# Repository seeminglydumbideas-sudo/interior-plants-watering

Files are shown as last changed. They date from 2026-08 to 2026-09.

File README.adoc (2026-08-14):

= Interior Plants Watering System

A comprehensive plant monitoring and automated watering system based on the ESP32 platform. This project consists of low-power Bluetooth Low Energy (BLE) moisture sensors distributed across your plants, and a central base station that aggregates data, provides a monitoring interface, and controls water pumps to keep your plants happy.

== Status

As of Summer 2026, active development is primarily focused on finalizing the sensor nodes. The immediate goals are to ensure their reliability and to design a 3D-printable enclosure for them. The central server does not yet control the water pumps; it currently features a minimal UI and exposes a Prometheus endpoint. For the time being, sensor data is observed and troubleshooted primarily via Grafana dashboards.

[cols="1,1,1", frame="none", grid="none"]
|===
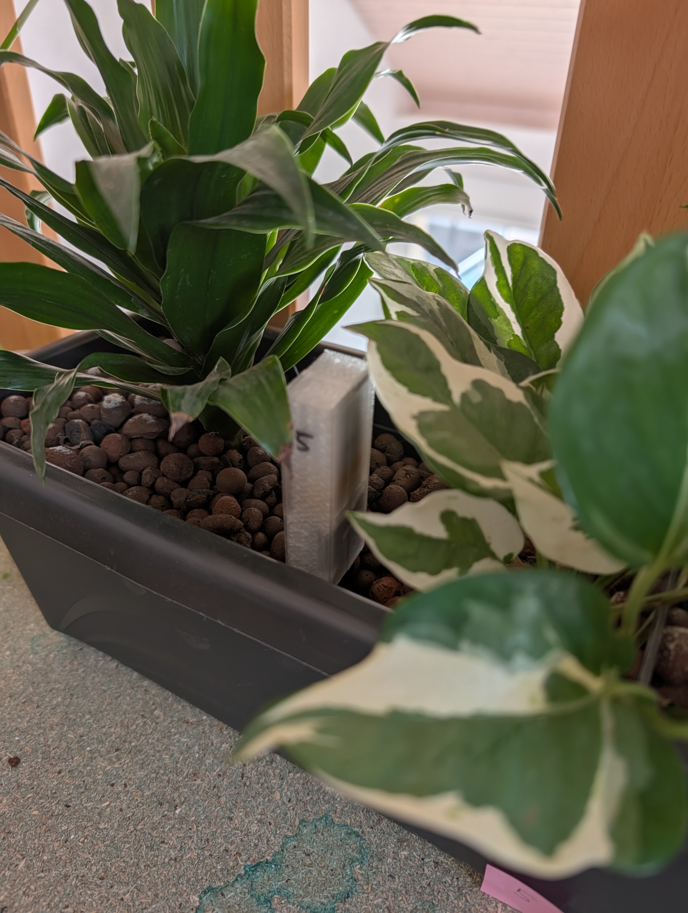
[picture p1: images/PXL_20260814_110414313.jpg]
| 
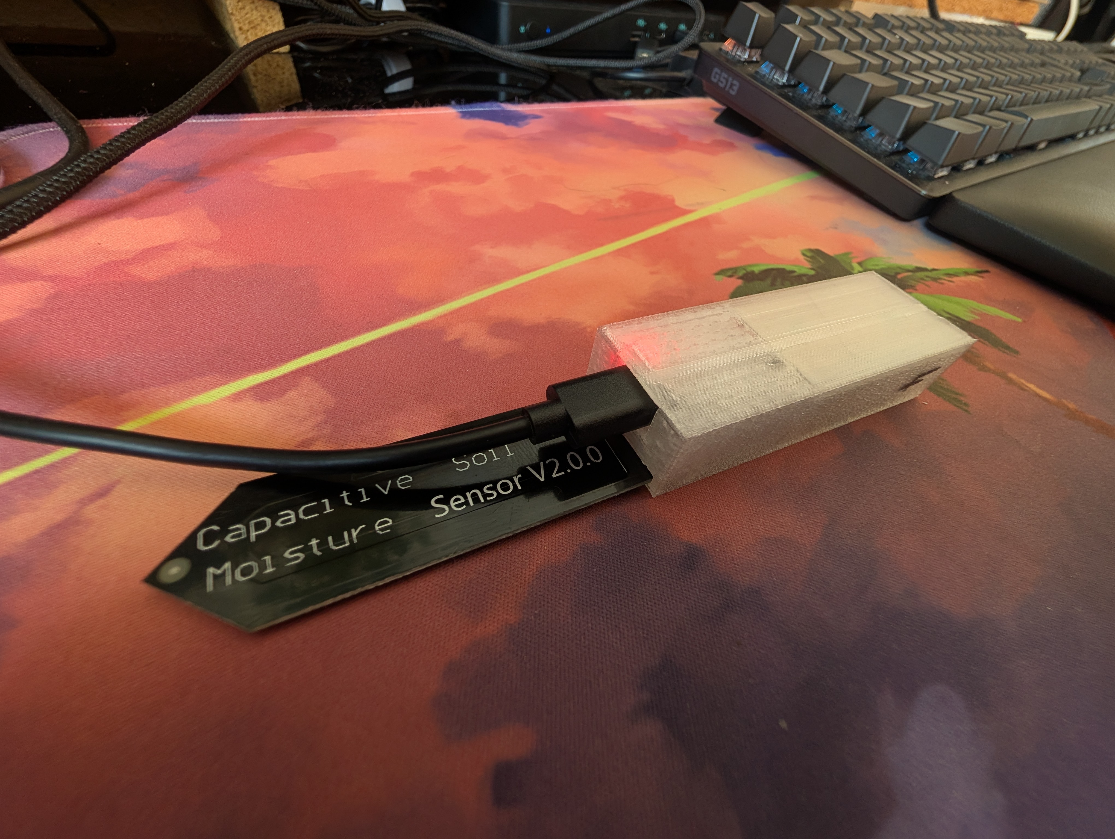
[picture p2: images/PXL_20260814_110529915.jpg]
| 
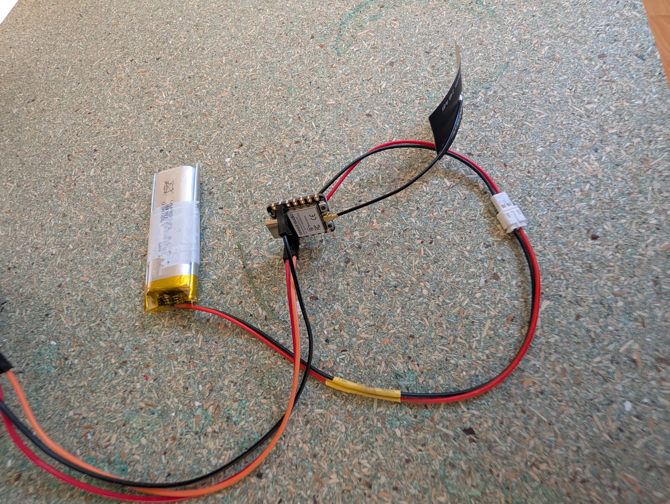
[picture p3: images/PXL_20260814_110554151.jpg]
| 

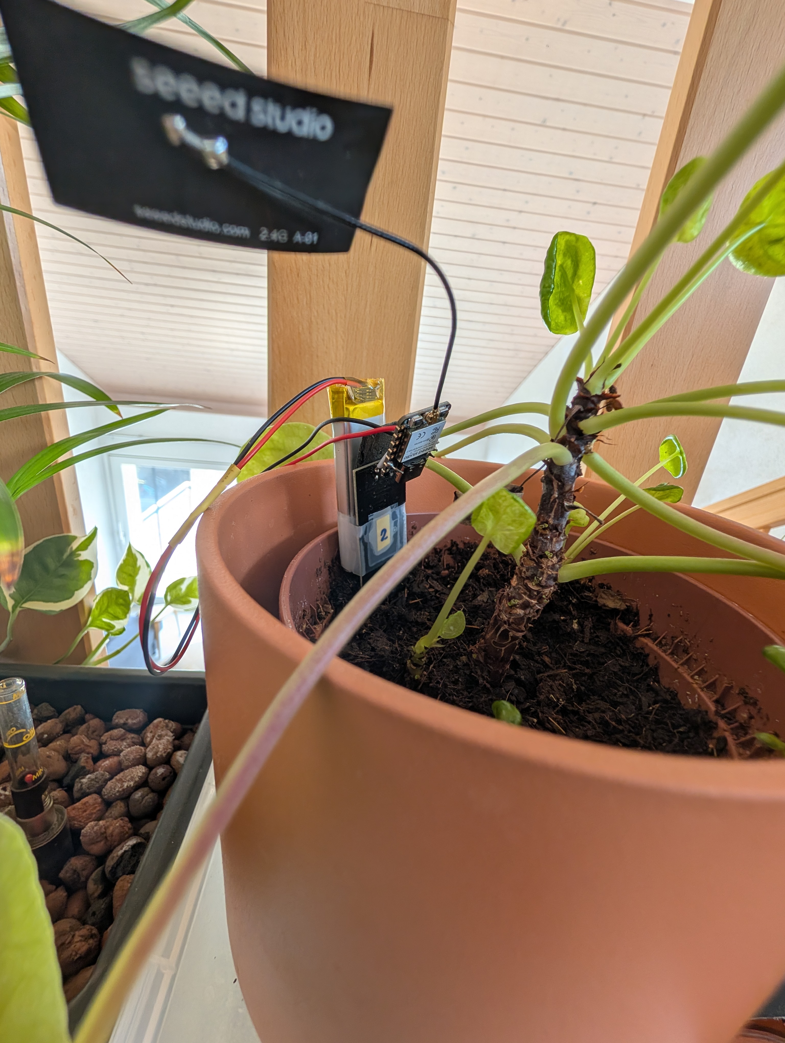
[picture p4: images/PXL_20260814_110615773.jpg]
| 
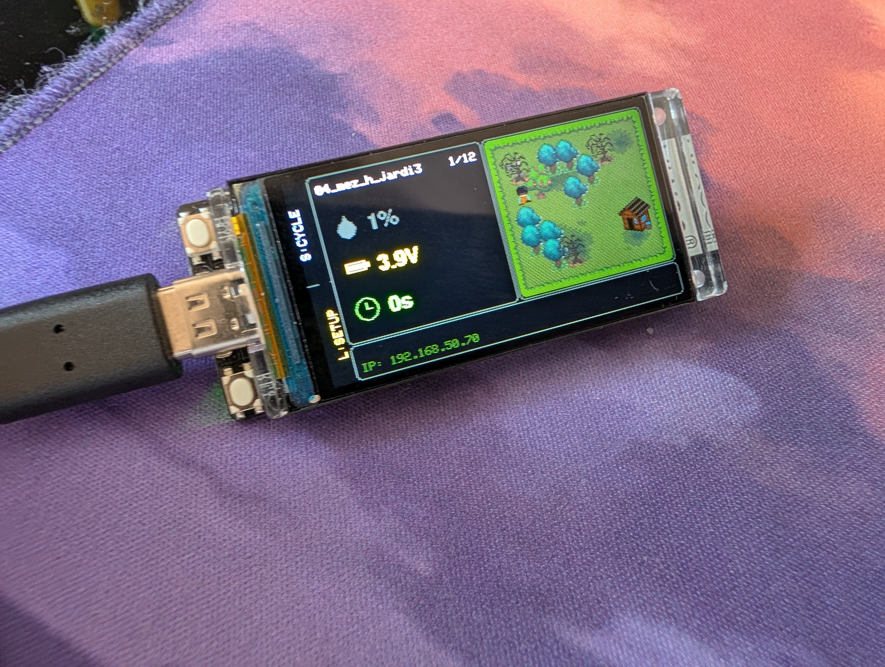
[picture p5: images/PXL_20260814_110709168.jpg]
| 
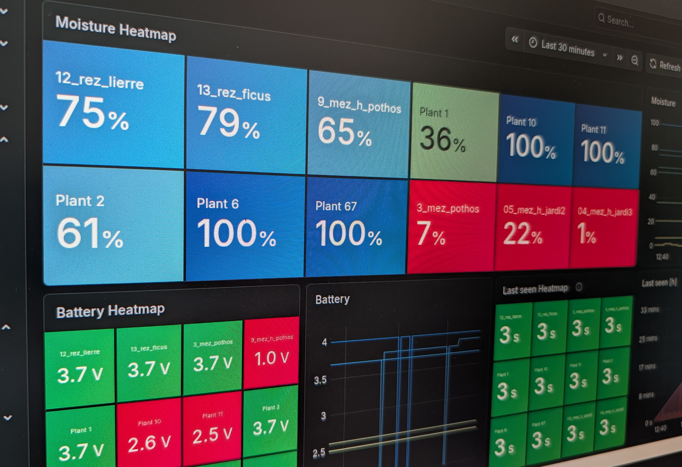
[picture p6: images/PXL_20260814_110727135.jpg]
| 
|===

== System Architecture

The system is split into two main components, which will be integrated into this repository:

=== 1. Plant Sensor (The "Nodes")
A low-power BLE soil moisture sensor node. Designed for battery-powered deployment, it spends most of its life in deep sleep, waking periodically to sample soil moisture and broadcast telemetry.

See the link:sensor/README.adoc[Sensor Documentation] for detailed hardware configuration, pinouts, and calibration instructions.

* *Hardware:* Seeed Studio XIAO ESP32-C3, Capacitive Soil Moisture Sensor v1.2, 3.7V LiPo battery.
* *Features:* 
** Broadcasts telemetry via BLE manufacturer advertisements (no active connection required).
** Auto-calibration of dry/wet bounds stored in NVS flash.
** Battery voltage monitoring and smart power management (differentiates between USB and battery).

=== 2. Plant Server (The "Base Station")
The central controller that scans for BLE advertisements from the sensors, displays their status, and triggers water pumps when plants get too dry.

* *Hardware:* LilyGo T-Display ESP32 (or ESP32-S3), 4-channel relay board, and water pumps.
* *Features:*
** *Monitoring UI:* A clean data-focused display to monitor the real-world sensors.
** *Automated Watering:* Controls relays based on moisture readings with safety cooldowns and scheduling logic.
** *Metrics:* Serves Prometheus metrics for monitoring via Grafana.
** *Persistence:* Thread-safe sensor data management with NVS persistence for configuration and last-watered times.

== How It Works

1. *Sensors* read capacitive moisture levels and broadcast the raw data, calibration bounds, and battery voltage over BLE using a specific Service UUID (`a1b2c3d4-0001-4c9a-8f2e-5a7b9e3d6f80`).
2. The *Server* continuously scans the BLE spectrum for these specific advertisements.
3. The *Server* parses the data, updates its internal thread-safe store, and updates the display.
4. If a sensor's moisture drops below a threshold, the *Server's* Gardener module activates the corresponding relay to run a water pump.

== Getting Started

Each component has its own specific build instructions, configuration, and hardware setup. Please refer to the respective subdirectories (once imported) for detailed setup and deployment instructions.

* *For deploying a new sensor node:* You will need a XIAO ESP32-C3 and the Arduino IDE / `arduino-cli` to compile and upload the firmware. See the link:sensor/README.adoc[Sensor Setup Guide].
* *For setting up the base station:* You will need a LilyGo T-Display, WiFi credentials (for metrics), and the appropriate Arduino libraries (like `TFT_eSPI` configured for your display).

== License

This project is licensed under the GNU General Public License v3.0 (GPL-3.0). See the LICENSE file for details.

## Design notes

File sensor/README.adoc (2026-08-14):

= plant-sensor-esp32

A low-power Bluetooth Low Energy (BLE) soil moisture sensor node built for the *Seeed Studio XIAO ESP32-C3*.

== Overview

`plant-sensor-esp32` periodically measures soil moisture levels, monitors battery voltage and power source, and broadcasts telemetry over BLE manufacturer advertisements. Designed for battery-powered deployment, the device spends most of its life in ESP32 deep sleep, waking up to sample sensors and advertise data to central receiver nodes (such as the Plant Server).

IMPORTANT: Sensors are designed to be used with a dedicated base station (not used directly with phones). See the link:../README.adoc[main project README] for details.

=== Hardware Components

* *Microcontroller:* Seeed Studio XIAO ESP32-C3 (RISC-V single-core @ 160MHz, 2.4GHz Wi-Fi & BLE 5.0)
* *Soil Moisture Sensor:* Capacitive Soil Moisture Sensor v1.2
* *Power Monitoring:* Voltage divider (2x 220kΩ resistors) connected to ADC pin `D2` / `A2`
* *Power Supply:* 3.7V LiPo / Li-Ion battery or USB-C (5V)

== Key Features

* *BLE Telemetry Broadcast:* Broadcasts sensor telemetry without requiring active connections. Scan response manufacturer data payload includes:
** Moisture percentage (`0–100%`, or uncalibrated indicator `0xFF`)
** Raw ADC reading, `rawMin`, and `rawMax` bounds
** Battery voltage (`V`) and power source (Battery vs. USB)
** RTC boot counter
** Filterable by Service UUID `a1b2c3d4-0001-4c9a-8f2e-5a7b9e3d6f80`
* *Capacitive Moisture Sampling:* Non-blocking async sampling state machine to power and sample the sensor safely. Automatically tracks calibration bounds and persists them to NVS flash (`Preferences`).
* *Smart Power Management:* Reads battery voltage via resistor divider on ADC pin `D2`, differentiates between USB and battery power, and controls ESP32 deep sleep cycles. Features a 2-minute safety window on cold power-on to allow seamless firmware reflashing.
* *Calibration Reset:* Press and hold the onboard *BOOT* button (GPIO 9) for 3 seconds to clear saved calibration bounds from flash memory.

== Pinout & Hardware Configuration

[cols="1,1,2", options="header"]
|===
| Component | Pin | Notes

| *Moisture Sensor VCC*
| `D0`
| Switched output to power sensor only during sampling

| *Moisture Sensor Signal*
| `D1`
| Analog input for moisture sensor reading

| *Battery Divider ADC*
| `D2` / `A2`
| Resistor divider input for voltage measurement

| *BOOT Button*
| `GPIO 9`
| Pulled HIGH internally; hold 3s to reset calibration
|===

== Calibration Procedure

The sensor uses automatic bound tracking to calculate soil moisture percentages from raw ADC readings. The bounds (`rawMin` and `rawMax`) are stored in NVS flash memory (`Preferences`). It will persist resets and re-deploy.

To calibrate a sensor:

1. *Wake Device:* Press the *RST button* (or power-cycle the board) to ensure the ESP32 is awake and not in deep sleep mode.
2. *Reset Calibration:* Press and hold the onboard *BOOT button (GPIO 9)* for 3 seconds. The serial output will log `[INFO] Moisture calibration reset`, clearing stored bounds (`rawMin = 4095`, `rawMax = 0`).
3. *Set Dry Bound (0%):* Expose the capacitive probe to dry air (or insert into completely dry soil) during a sample cycle (typically 2-4 minutes). The highest ADC value measured will automatically be saved as `rawMax`.
4. *Set Wet Bound (100%):* Submerge the probe in water up to the max fill line (or insert into fully saturated soil) during a sample cycle. The lowest ADC value measured will automatically be saved as `rawMin`.
5. *Automatic Calculation:* Once `rawMax > rawMin + 500`, the firmware calculates moisture as:
+
[source,cpp]
----
moisture % = 100 - ((100 * (rawValue - rawMin)) / (rawMax - rawMin))
----
+
Updated calibration bounds are saved to flash memory automatically whenever new minimums or maximums are detected.

== Build & Deployment

Use the provided `deploy.sh` script (located in the `bin/` directory) to compile, upload, and monitor. Make sure to run it from inside the `sensor/` directory:

[source,bash]
----
# Compile and upload specifying the SENSOR_ID
SENSOR_ID=13_rez_ficus ./bin/deploy.sh /dev/ttyACM0

# Compile only
SENSOR_ID=13_rez_ficus ./bin/deploy.sh --compile-only
----

The script automatically generates `Secrets.cpp` containing your specified `SENSOR_ID` and attaches to the serial monitor.

== License

This project is licensed under the GNU General Public License v3.0 (GPL-3.0) - see the link:../LICENSE[LICENSE] file in the root directory for details.

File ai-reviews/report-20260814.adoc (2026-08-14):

= AI Pre-Commit Review Report: Interior Plants Watering
:date: 2026-08-14
:author: Antigravity AI
:toc:

== 1. Privacy, Security & Secrets (AGENTS.md Checklist)
=== 1.1 Hardcoded Secrets
* [PASS] No hardcoded passwords, SSIDs, or API tokens were found leaked in the repository.
* [PASS] `Secrets.h` is used properly for definitions, while `Secrets.cpp` is kept out of source control.
* [NOTE] In `.gitignore`, `Secrets.cpp` is listed twice (lines 2 and 3). This is harmless but could be cleaned up.

=== 1.2 PII & Absolute Paths
* [PASS] No absolute local paths (`/home/user/...`), usernames, or IP leaks were detected in the source code or scripts.

=== 1.3 Media Metadata (EXIF)
* [WARNING] Several `.jpg` and `.png` files in the `images/` and `sensor/3d_case/` directories still contain residual EXIF metadata (e.g., `Modify Date`, `Pixels Per Unit`, `Image Size`).
  * **Recommendation:** Run `find . -type f -name "*.png" -o -name "*.jpg" | xargs exiftool -all=` from the root directory before committing to adhere strictly to the Open Source Checklist.

== 2. Code Architecture & Power Management (`sensor-firmware`)
=== 2.1 Deep Sleep Implementation
* [PASS] `PowerManager.cpp` correctly implements deep sleep using `esp_deep_sleep_start()`.
* [PASS] The system appropriately uses `RTC_DATA_ATTR` for variables like `bootCount` and `totalElapsedSec` to survive deep sleep cycles and reset only on cold power cycles.

=== 2.2 Non-Blocking Architecture
* [PASS] `sensor-firmware.ino` avoids blocking `delay()` loops for its core state machine, cleanly separating logic across `power.loop()`, `moisture.loop()`, `bluetooth.loop()`, and `sensor.loop()`.
* [PASS] The broadcast window relies on `millis()` tracking (`millis() - _dataReadyAt < BROADCAST_WINDOW_MS`) before entering deep sleep, ensuring BLE packets have time to transmit.

=== 2.3 Hardware Interfaces
* [PASS] Voltage readings correctly take attenuation and multi-sampling into account in `PowerManager::getLevel()`.

== 3. Documentation
* [PASS] `README.adoc` provides excellent, comprehensive overviews of both the Sensor ("Nodes") and the Server ("Base Station") components.
* [PASS] The documentation accurately reflects the current state of development (Summer 2026, pumps disabled, Prometheus/Grafana focus).

== Summary & Recommendations
The `interior-plants-watering` sensor implementation is very clean, utilizing proper low-power design patterns for the ESP32-C3. 

**Action Item Before Commit:** Scrub the remaining EXIF data from the image directories.

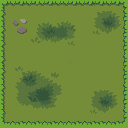
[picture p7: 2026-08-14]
server/server-firmware/sprites/scene.png

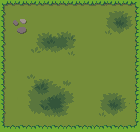
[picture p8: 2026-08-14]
server/server-firmware/sprites/scene2.png

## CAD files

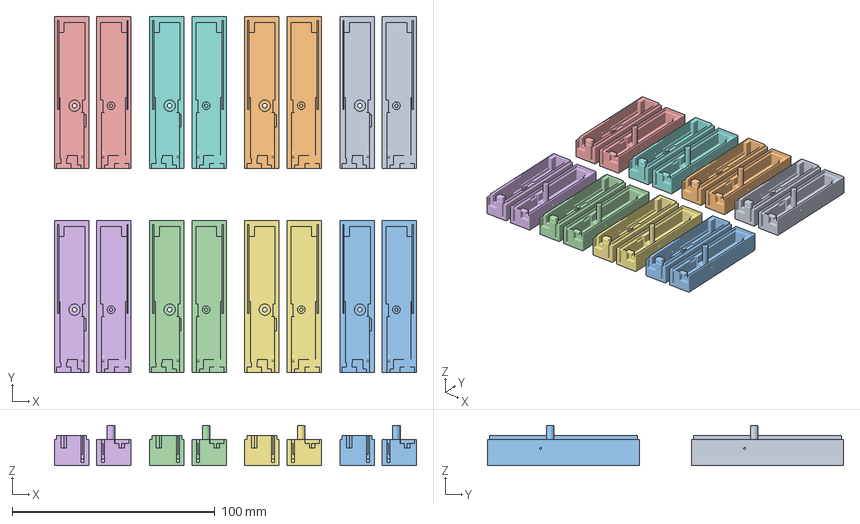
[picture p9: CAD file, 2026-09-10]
sensor/3d_case/plant_v8.2/plant_v8.2.3mf
178.5 x 175.6 x 19.9 mm
plant_8,2.stl x 5
plant_8,2.stl 1
plant_8,2.stl 6
plant_8,2.stl 4

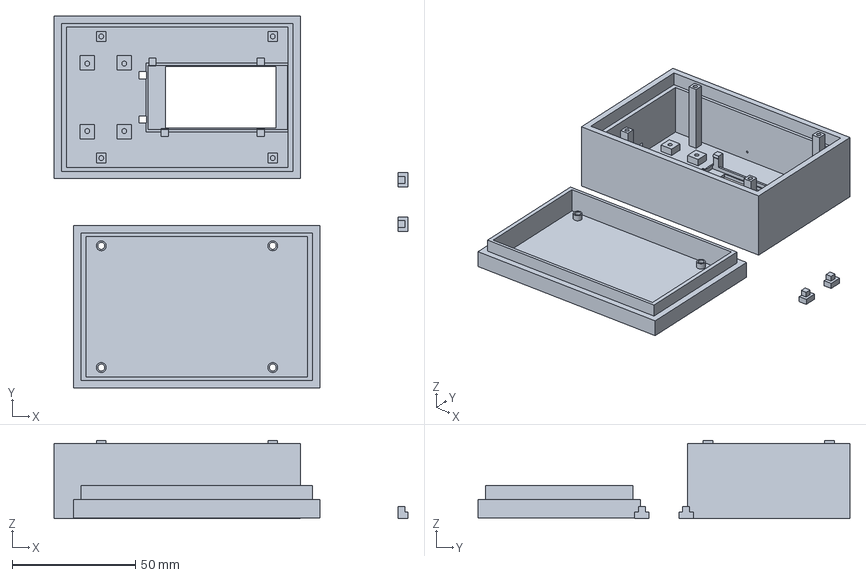
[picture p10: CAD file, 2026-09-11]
server/3d_case/pltsrv_v1.1/pltsrv_v1.1.3mf
143.7 x 151.0 x 31.7 mm

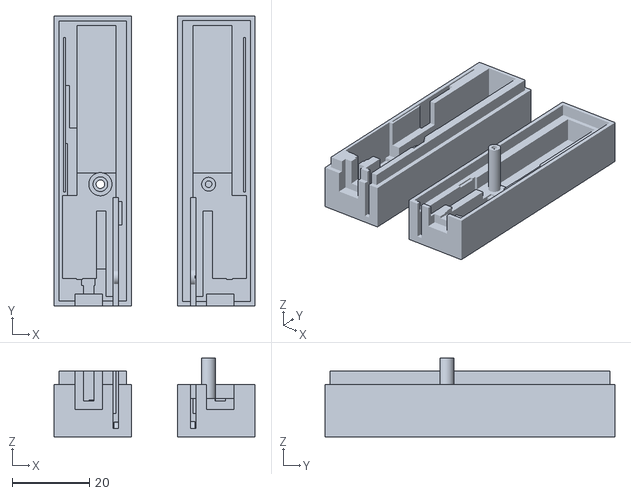
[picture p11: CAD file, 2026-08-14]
sensor/3d_case/plant_v7.x/plant_v7.0-fat.stl
52.0 x 75.0 x 20.4

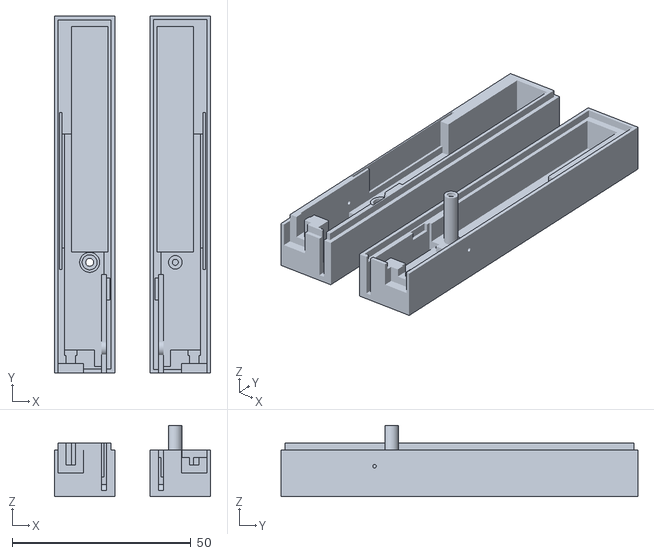
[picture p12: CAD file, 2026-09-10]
sensor/3d_case/plant_v8.2/plant_8,2-large_battery.stl
43.8 x 100.0 x 19.9

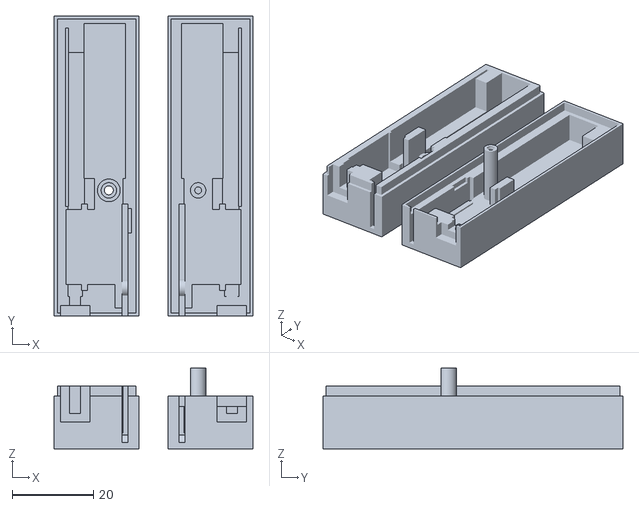
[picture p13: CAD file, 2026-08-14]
sensor/3d_case/plant_v7.x/plant_v7.5-avoid_thin_walls.stl
48.9 x 73.9 x 19.8

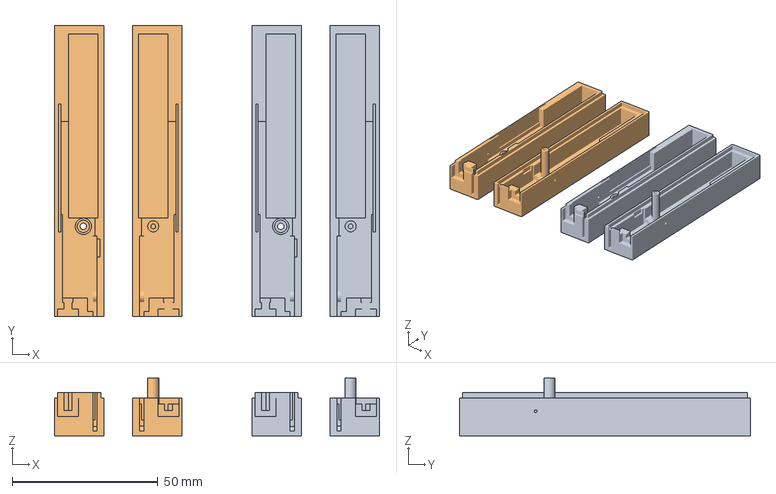
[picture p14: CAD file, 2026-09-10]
sensor/3d_case/plant_v8.2/plant_v8.2_large-battery.3mf
111.6 x 100.0 x 19.9 mm
plant_8,2-large_battery.stl x 2

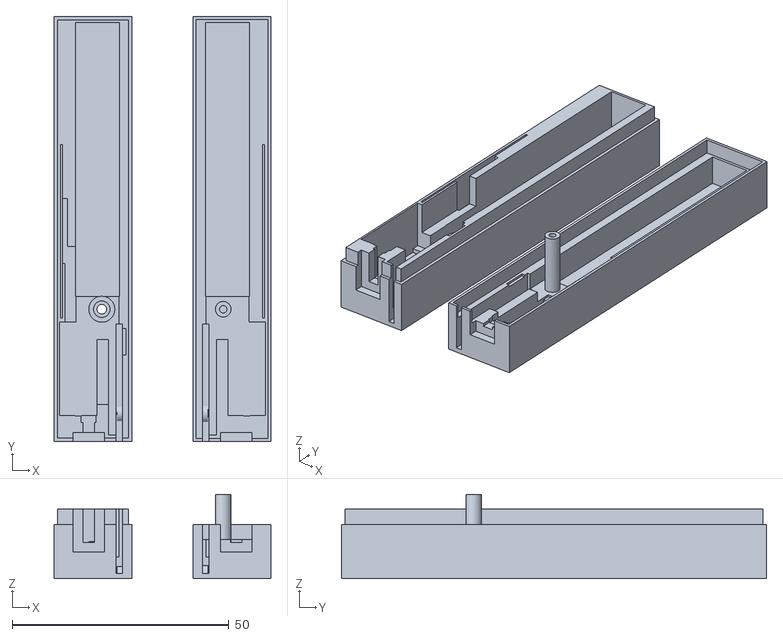
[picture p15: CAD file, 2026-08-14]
sensor/3d_case/plant_v7.x/plant_v7.0-large.stl
50.0 x 98.0 x 19.4

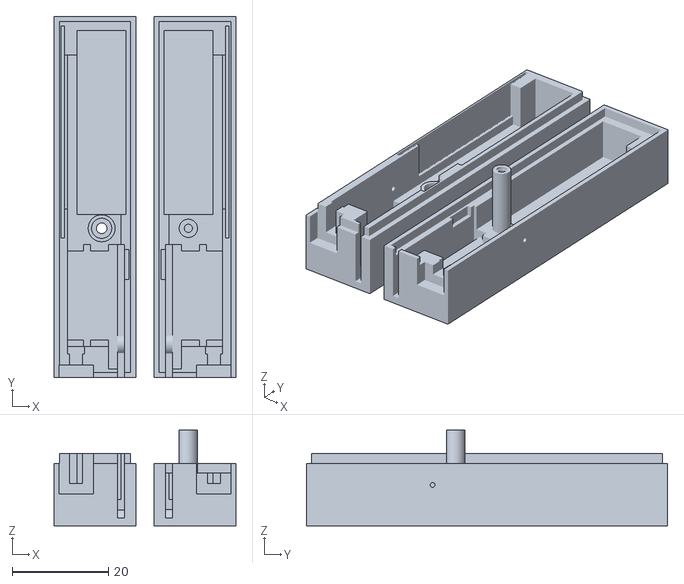
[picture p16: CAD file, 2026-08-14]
sensor/3d_case/plant_v8.2/plant_8,2.stl
37.8 x 75.0 x 19.9

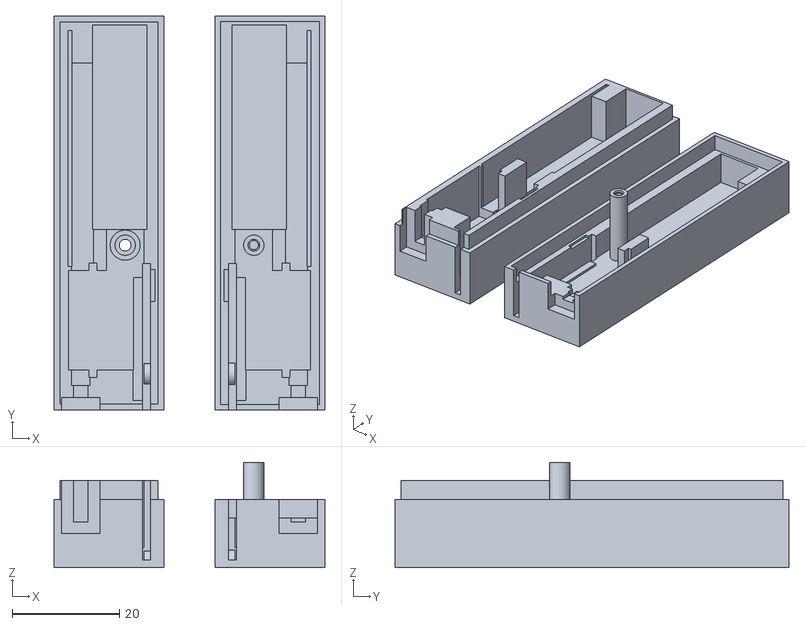
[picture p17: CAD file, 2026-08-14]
sensor/3d_case/plant_v7.x/plant_v7.4.stl
50.5 x 73.5 x 19.6

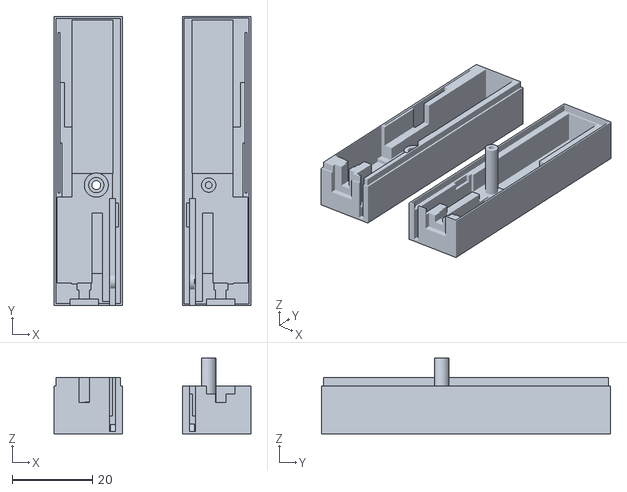
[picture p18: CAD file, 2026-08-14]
sensor/3d_case/plant_v7.x/plant_v7.0-thin.stl
49.0 x 72.0 x 18.9

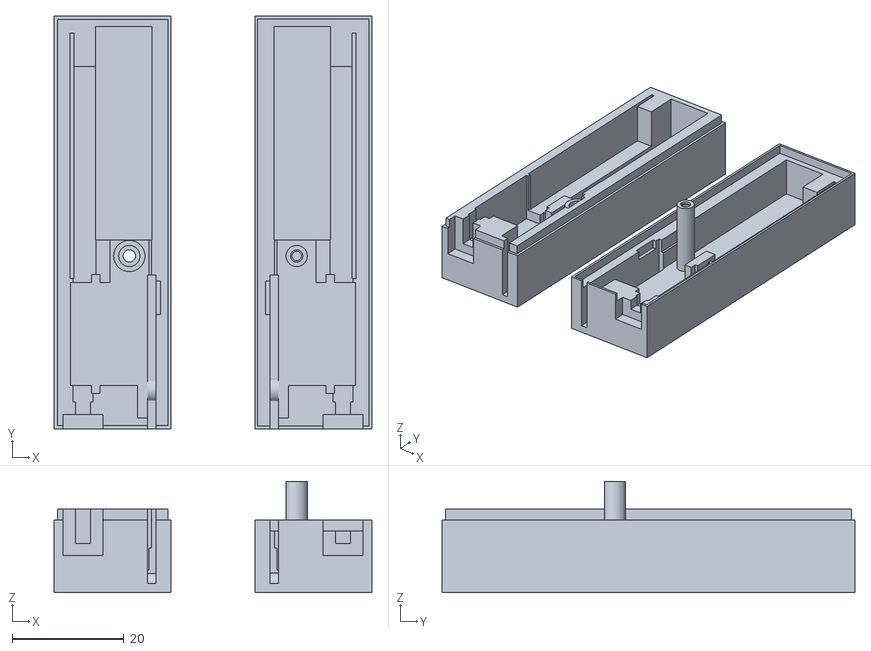
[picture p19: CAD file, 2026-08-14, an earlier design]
sensor/3d_case/plant_v8.0/plant_8.0-avoid-thin-walls.stl
57.0 x 74.0 x 19.9

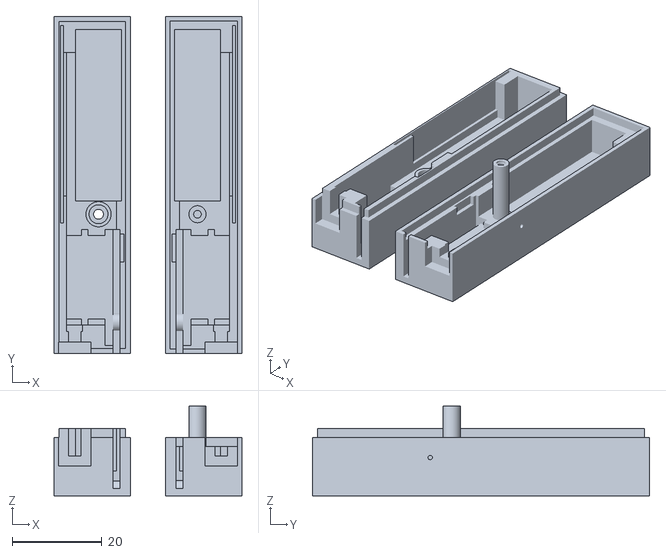
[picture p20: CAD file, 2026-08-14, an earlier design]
sensor/3d_case/plant_v8.1/plant_8.1.stl
41.8 x 75.0 x 19.9

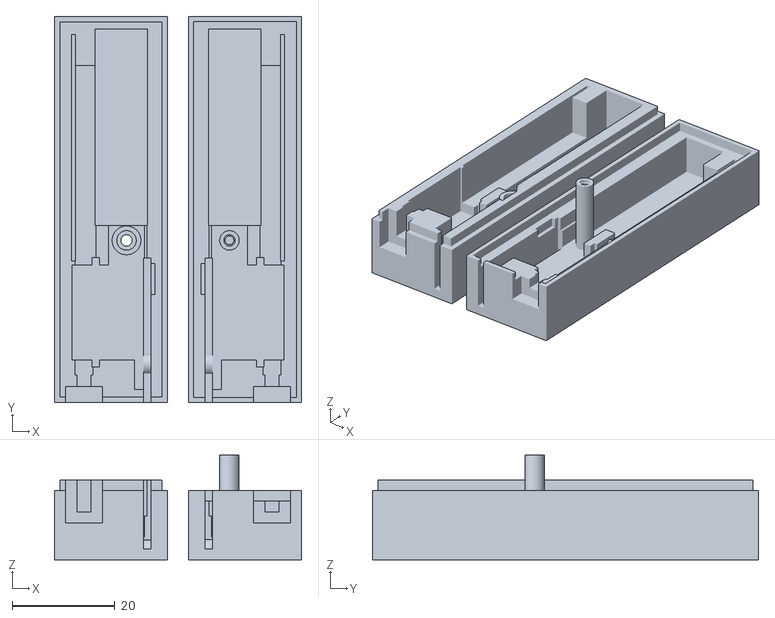
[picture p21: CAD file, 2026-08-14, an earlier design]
sensor/3d_case/plant_v8.0/plant_8.0-avoid-thin-walls-2.stl
48.0 x 75.0 x 20.4

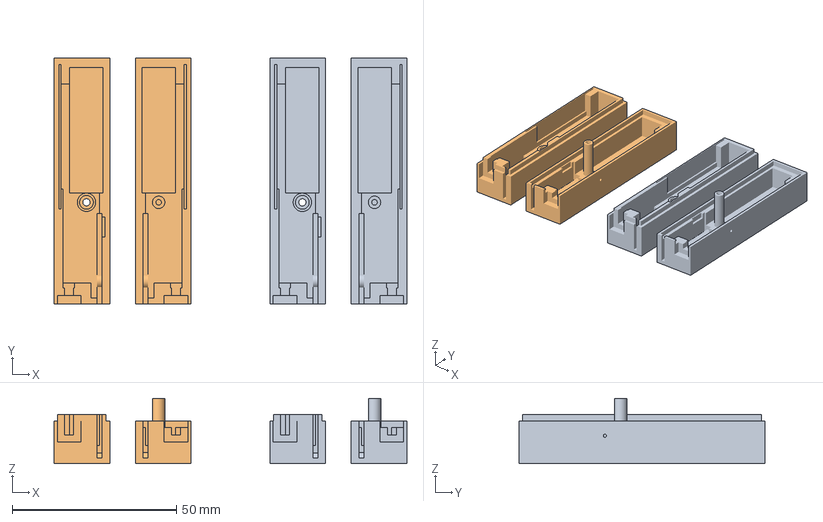
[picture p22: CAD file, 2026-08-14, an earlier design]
sensor/3d_case/plant_v8.1/plant_v8.1.3mf
107.6 x 75.0 x 19.9 mm
plant_8.1.stl x 2

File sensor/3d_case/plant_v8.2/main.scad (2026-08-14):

use <MCAD/boxes.scad>
use <sensor.scad>
use <holes.scad>

/*[ Rendering ]*/
//poly quality
$fn=100; // [100:high,6:low]

//Type of battery (lenght)
_batLg=38; // [38:600mAh (small),63:1200mAh (large)]
// Volume Increased
_vol_inc=2;// [-2:0.1:5]
// Edge Depth
_edge_depth=2;// [1:0.25:10]
// Edge Border
_edge_width=1;// [0.1:0.1:3]

// Opening
_opening=20;// [0:1:60]

// Left
_left=true;
// Right
_right=true;
// Model
_model=true;
// Model
_print=false;


// ================
// VOL
// ================
module right_insert(main_pos,main_vol,edge_depth,edge_width,tol=0) {
 translate([
    main_pos[0],
    main_pos[1],
    main_pos[2]]){
  cube([
    edge_depth*2,
    main_vol[1]-2*edge_width-2*tol,
    main_vol[2]-2*edge_width-2*tol],center=true);
 }
}

module volume_right(main_pos,main_vol,edge_depth,edge_width,tol=0) {
 // main volume
 difference() {
  translate(main_pos){
   cube(main_vol,center=true);
  };
  // remove left side
  translate([main_pos[0]+100,0,0]){
   cube([200,200,200],center=true);
  };
 }
 // "right insert": the part that is smaller 
 // and go inside case_left
 right_insert(main_pos,main_vol,edge_depth,edge_width,tol); 
}

module volume_left(main_pos,main_vol,edge_depth,edge_width) {
 // main volume
 difference() {
  translate(main_pos){
   cube(main_vol,center=true);
  };
  // remove left side
  translate([main_pos[0]-100,0,0]){
   cube([200,200,100],center=true);
  };
  // make place for the "right insert" () see case_right()
  right_insert(main_pos,main_vol,edge_depth, edge_width, 0);
 }
}

// ================
// CASE
// ================

module hole_screw_m2() {
  // hole for thread
  //translate([-2,7,-3])
  translate([0,0,-3.6])
   cylinder(h=8,r=1.7/2,center=true);
  // hole no thread
  translate([0,0,-8.5]) 
   cylinder(h=2,r=2.2/2,center=true);
  // hole for head
  translate([0,0,-12.5]) 
   cylinder(h=8,r=3.4/2,center=true);
}

SCREW_Z=4;

module case_left(main_pos,main_vol,edge_depth,edge_width,battery_length) {    
    

 // volume - hole
 difference() {    
    volume_left(main_pos,main_vol,edge_depth,edge_width);
    hole_model(battery_length);
    // pinhole : boot button position
    translate([4.5,2.2,13])
      cylinder(h=10,d=1,center=true);       
 } 
 // things to hold sensor
 difference() {
  translate([11.6,-17,-0.5]) // (8.1) fix bascule issue
   cylinder(h=3,r=2,center=true);
  translate([14,-17,0])
   cube([5,5,6], center=true);
 }
 // long stuff for screw - screw hole
 translate([1.1,7,SCREW_Z])
   rotate([0,90,0])
     difference() {
       cylinder(h=16,r=1.9,center=true);
       hole_screw_m2();
     }
}

module case_right(main_pos,main_vol,edge_depth,edge_width,edge_tol,battery_length) {
 // volume-holes-hole_screw    
 difference() {
    volume_right(main_pos,main_vol,edge_depth,edge_width,edge_tol);
    hole_model(battery_length);
    translate([0.6,7,SCREW_Z])
     rotate([0,90,0])
       hole_screw_m2();
    // pinhole : boot button position
    translate([-4.5,2.2,13])
      cylinder(h=10,d=1,center=true);       
     
 } 
 // things to hold sensor
 difference() {
  translate([-11.6,-17,-0.5]) // (8.1) fix bascule issue
   cylinder(h=3,r=1.9,center=true);
  translate([-14,-17,0])
   cube([5,5,6], center=true);
 }
 // hole for screw (with head stop)
 difference() { 
  translate([-8,7,SCREW_Z])
   rotate([0,90,0])
     cylinder(h=8,r=2.8,center=true);
   // remove hole for screw
   translate([0.6,7,SCREW_Z])
     rotate([0,90,0])
       hole_screw_m2();
   // remove insert for long stuf
   translate([0.5,7,SCREW_Z])
     rotate([0,90,0])
      cylinder(h=15,r=2.1,center=true); // -> (8.1) make it larger since it was to tight
 }

}
// ================
// DEBUG
// ================
module view_left_case(batLg) {
 color("#c0c0c0")
  model(batLg);
 case_left(_pos,_vol,_edge_depth,_edge_width,batLg);    
}

module view_right_case(batLg) {
 color("#c0c0c0")
  model(batLg);
 case_right(_pos,_vol,_edge_depth,_edge_width,_edge_tol,batLg);  
}

module view_both_cases(pos,vol,ed,ew,et,bl,space,space=20) {
 if (_right)
   translate([-space,0,0])
    color("#a060a0",1)
     case_right(pos,vol,ed,ew,et,bl);    
 if (_left)
  translate([space,0,0])
   color("#60a0a0",1)
    case_left(pos,vol,ed,ew,bl);
}
    
module view_up(pos,vol,ed,ew,et,bl,space,cut) {
 difference() {
  view_both_cases(pos,vol,ed,ew,et,bl,space);
  translate([-150,-150,cut]) 
   cube([300,300,300]);
 }
}

module view_print(pos,vol,ed,ew,et,bl,space) {
 rotate([0,-90,0])
  translate([10,0,space])
   color("#a060a0",1)
    case_right(pos,vol,ed,ew,et,bl);    
 rotate([0,90,0])
  translate([-10,0,space])
    color("#60a0a0",1)
     case_left(pos,vol,ed,ew,bl);
}

// ================
// MAIN
// ================

_pos=[0 , -5.5+_batLg/2, 5.4];
_vol=[24, 35+_batLg,  15];
_edge_tol=0.1;

// DEBUG insert only
//volume_right(_pos,_vol,_edge_depth,_edge_width,_edge_tol); 
//volume_left(_pos,_vol,_edge_depth,_edge_width);

// DEBUG cuts
//view_up(_pos,_vol,_edge_depth,_edge_width,_edge_tol,_batLg, 0, SCREW_Z); // focus: screw
//view_up(_pos,_vol,_edge_depth,_edge_width,_edge_tol,_batLg, 0, 10); // focus: ??
//view_up(_pos,_vol,_edge_depth,_edge_width,_edge_tol,_batLg, 0, 0); // focus: sensor


// Normal view 
if (_right || _left) view_both_cases(_pos,inc(_vol,_vol_inc),_edge_depth,_edge_width,_edge_tol,_batLg, _opening);
if (_print)
    view_print(_pos,inc(_vol,_vol_inc),_edge_depth,_edge_width,_edge_tol,_batLg, _opening);

 if (_model)
  color("#a09090",0.5)
    model(_batLg);
 
 
 

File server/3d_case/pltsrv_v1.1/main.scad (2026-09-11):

use <sub_hw-316_4relays.scad>
use <sub_lilygo_t_display_s3.scad>
use <usb-debug-pcb.scad>

/*[ Rendering ]*/
//poly quality
$fn=100; // [100:high,6:low]

// Cross-section cut X (viewing only)
_cut_x = -60; // [-60:0.5:60]
// Cross-section cut Y (viewing only)
_cut_y = -60; // [-60:1:60]
// Cross-section cut Z (viewing only)
_cut_z = -60; // [-60:1:60]
// Opening: distance to separate top/bottom for viewing
_top_open = 20; // [0:1:80]
// Gap between pieces when laid out for print
_print_gap = 20; // [0:1:60]

// Top
_top=true;
// Bottom
_bottom=true;
// Model up (reference components housed in the top: ESP + USB debug pcb)
_model_up=true;
// Model down (reference components housed in the bottom: relay module)
_model_down=true;
// Print layout (lay both halves flat, ready to slice)
_print=false;

/*[ Display clip ]*/
// how far the barb reaches inward over the pcb edge. Post sits 1.65mm
// outside the pcb's y edge at y=+-12.85, but the display_hole cut already
// removes material starting at y=+-12.5, so there's only ~0.35mm of
// window to reach into before this starts getting sliced by that cut.
// Keep this between 0.15 (barely clears the hole) and 0.5 (barely reaches
// the pcb edge); 0.3 splits the difference but is a thin, unverified
// margin -- retune against the real board/print.
_dclip_protrusion = 1; // [0:0.05:0.5]
// height of the lead-in ramp (insertion side, cammed over on the way up)
_dclip_ramp_h = 1.0; // [0.2:0.1:3]
// height of the steep catch face (retention side, holds the pcb once past)
_dclip_catch_h = 0.4; // [0.1:0.1:2]
// z where the ramp starts (just above the post tip)
_dclip_base_z = 10; // [8:0.1:16]


// Barb on one display-corner post so the display pcb clips past it when
// pushed up into place instead of just resting loose on the posts.
// x,y: same corner position as the post. dir: +1 or -1, which way (y) the
// barb reaches inward over the pcb -- the post sits just outside the pcb's
// y edge (post y=+-14.5 vs pcb edge y=+-12.85), so the barb is attached to
// the post's y-facing side, not its x-facing side.
// Profile (in y-z, extruded along the post's x width): flush at the base,
// ramps inward to its max protrusion, then drops back to flush over a much
// shorter height -- a shallow lead-in ramp on the way up, a steep catch
// face once past. Assumes the bare pcb (61x25.7x1.2mm, see
// esp32_lilygo_t_display_s3()) sits with its bottom face around z=11.4 when
// the top is fully assembled (_top_open=0) -- verify against the real
// board/print and retune the _dclip_* params above if the fit is off.
module display_clip(x,y,dir) {
  translate([x, y + dir*1.5, _dclip_base_z])
    rotate([0,0,90])
      rotate([90,0,0])
        linear_extrude(height=3, center=true)
          polygon(points=[
            [0,0],
            [dir*_dclip_protrusion, _dclip_ramp_h],
            [0, _dclip_ramp_h+_dclip_catch_h]
          ]);
}


module box_bottom(main_pos,main_vol,hcut,insert_width,insert_height,insert_tol) {
  //https://www.handsontec.com/dataspecs/4Ch-relay.pdf
  holes=[69.6,49.4,3];
  // compute bottom H+Z
  h=hcut*main_vol[2];
  z=(main_pos[2]-main_vol[2]+h)/2;
  difference() {
    union() {
      difference() {
      // bottom + insert
       union() {
         // bottom volume
         translate([main_pos[0],main_pos[1],main_pos[2]+z]){
           cube([main_vol[0],main_vol[1],h],center=true);
         };
         // insert
         iz=z+h/2+insert_height/2-insert_tol;
         translate([main_pos[0],main_pos[1],iz]){
           cube([
             main_vol[0]-2*insert_width-2*insert_tol,
             main_vol[1]-2*insert_width-2*insert_tol,
             insert_height],
             center=true);
          };
        };
        // big hole for PCB (x widened +4.9 to 94.9, matches box_top's
        // large hole -- see main_vol/main_pos comment in main.scad)
        translate([main_pos[0],main_pos[1],main_pos[2]]){
            cube([
                94.9,
                57,
                main_vol[2]-5
            ],center=true);
        };
      };
      // support for replay PCB. The narrower r=1.3 peg (poking up above
      // the r=2 shelf, into the pcb's mounting hole) was shortened
      // (z=-14->-14.5, h=2.9->1.9) to make room for box_top's new
      // locating peg reaching down into the same hole from above --
      // its top is now flush with the shelf (z=-13.55) instead of
      // poking up to z=-12.55, leaving ~0.13mm clearance to that peg.
      translate([holes[0]/2,-holes[1]/2,-15])
        cylinder(h=2.9,r=2, center=true);
      translate([holes[0]/2,-holes[1]/2,-14.5])
        cylinder(h=1.9,r=1.3, center=true);

      translate([-holes[0]/2,-holes[1]/2,-15])
        cylinder(h=2.9,r=2, center=true);
      translate([-holes[0]/2,-holes[1]/2,-14.5])
        cylinder(h=1.9,r=1.3, center=true);

      translate([-holes[0]/2,holes[1]/2,-15])
        cylinder(h=2.9,r=2, center=true);
      translate([-holes[0]/2,holes[1]/2,-14.5])
        cylinder(h=1.9,r=1.3, center=true);

      translate([holes[0]/2,holes[1]/2,-15])
        cylinder(h=2.9,r=2, center=true);
      translate([holes[0]/2,holes[1]/2,-14.5])
        cylinder(h=1.9,r=1.3, center=true);
    }

    // screw holes
    translate([-holes[0]/2,holes[1]/2,-15])
      cylinder(h=10,r=1.4,center=true);
    translate([-holes[0]/2,-holes[1]/2,-15])
      cylinder(h=10,r=1.4,center=true);
    translate([holes[0]/2,-holes[1]/2,-15])
      cylinder(h=10,r=1.4,center=true);
    translate([holes[0]/2,holes[1]/2,-15])
      cylinder(h=10,r=1.4,center=true);

    translate([-holes[0]/2,holes[1]/2,-17.9])
      cylinder(h=1.5,r=2.2,center=true);
    translate([-holes[0]/2,-holes[1]/2,-17.9])
      cylinder(h=1.5,r=2.2,center=true);
    translate([holes[0]/2,-holes[1]/2,-17.9])
      cylinder(h=1.5,r=2.2,center=true);
    translate([holes[0]/2,holes[1]/2,-17.9])
      cylinder(h=1.5,r=2.2,center=true);

    // pump cable holes: 4x d=3.6mm through the -y wall, for the relay
    // outputs' cables running out to the pumps. Evenly spaced across
    // the relay board's own width (66.5mm -- see the "relays" cube in
    // sub_hw-316_4relays.scad); the model doesn't capture individual
    // terminal positions, so check against the real board and retune
    // x/z if the terminals land somewhere else.
    // z raised +15 (-14 -> 1) since the original position was too low;
    // needed hcut raised (0.2 -> 0.6, see main_pos/main_vol/hcut
    // comment) so box_bottom's wall is tall enough to still be solid
    // there (new ceiling ~4.25, ~3.25mm above this hole).
    translate([-24.9,-31,1])
      rotate([90,0,0])
        cylinder(h=10,d=3.6,center=true);
    translate([-8.3,-31,1])
      rotate([90,0,0])
        cylinder(h=10,d=3.6,center=true);
    translate([8.3,-31,1])
      rotate([90,0,0])
        cylinder(h=10,d=3.6,center=true);
    translate([24.9,-31,1])
      rotate([90,0,0])
        cylinder(h=10,d=3.6,center=true);

  }
}


module box_top_buttons(main_pos,main_vol,hcut,insert_width,insert_height,insert_tol) {
  // buttons
  // base (the large part) made 0.5mm thinner (2.6 -> 2.1) since it was
  // pressing too hard against the pcb's own button. Kept its top face
  // fixed at z=17.7 (where it merges with the stem) and shortened it
  // from the bottom instead, so the face that contacts the pcb button
  // sits 0.5mm higher (z=15.1 -> 15.6) -- less preload.
  // The stem originally shared that same bottom face (z=15.1) -- left
  // alone, its narrower tip would now poke out below the base as the
  // new (and only, and much smaller) contact point, which isn't what
  // "thinner" should do. Shortened it by the same 0.5mm (keeping its
  // top fixed, where it pokes out through the case) so both stay flush.
  translate([18,9,17.85])
    cube([2.6,2.6,4.5],center=true);
  translate([18.7,9,16.65])
    cube([4,6,2.1],center=true);

  translate([18,-9,17.85])
    cube([2.6,2.6,4.5],center=true);
  translate([18.7,-9,16.65])
    cube([4,6,2.1],center=true);

}


module box_top(main_pos,main_vol,hcut,insert_width,insert_height,insert_tol) {
 // compute bottom H+Z
 h=(1-hcut)*main_vol[2];
 z=(main_vol[2]-h)/2;
 holes=[69.6,49.4,3];
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

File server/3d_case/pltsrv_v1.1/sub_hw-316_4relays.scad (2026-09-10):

module hw_316() {
    //https://www.handsontec.com/dataspecs/4Ch-relay.pdf
    pcb=[76,56,1.1];
    holes=[69.6,49.4,3];
    relays=[66.5,27.5,15.5];
    
    union() {       
      // PCB-holes
      difference() {
        // PCB
        cube(pcb, center=true);           
        // holes
        translate([holes[0]/2,holes[1]/2,0])
          cylinder(h=2,r=holes[2]/2,center=true);
        translate([-holes[0]/2,holes[1]/2,0])
          cylinder(h=2,r=holes[2]/2,center=true);
        translate([holes[0]/2,-holes[1]/2,0])
          cylinder(h=2,r=holes[2]/2,center=true);
        translate([-holes[0]/2,-holes[1]/2,0])
          cylinder(h=2,r=holes[2]/2,center=true);
      }
      // relays
      translate([0,-(pcb[1]-relays[1])/2+5,relays[2]/2+0.5])
        cube(relays, center=true);
      // connectors
      translate([-22,20,13])
        cube([16,10,25], center=true);
      // bottom safe space
      translate([0,0,-1])
        cube([pcb[0]-1,pcb[1]-12,1], center=true);
      translate([0,0,-1])
        cube([pcb[0]-12,pcb[1]-1,1], center=true);
    }
}


color("#30AAAA")
  hw_316();

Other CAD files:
sensor/3d_case/plant_v7.x/plant_v7.3.gcode.3mf
sensor/3d_case/plant_v7.x/plant_v7.2.3mf
sensor/3d_case/plant_v8.0/plant_v8.0.3mf
sensor/3d_case/plant_v7.x/plant_v7.4-avoid_thin_walls.stl
server/3d_case/pltsrv_v1.1/sub_lilygo_t_display.scad
sensor/3d_case/plant_v7.x/model_plant_holes.scad
sensor/3d_case/plant_v7.x/model_plant_sensor.scad
sensor/3d_case/plant_v7.x/plant_v7.0.scad
sensor/3d_case/plant_v7.x/plant_v7.0.stl
sensor/3d_case/plant_v7.x/plant_v7.1.scad
sensor/3d_case/plant_v7.x/plant_v7.2.gcode.3mf
sensor/3d_case/plant_v7.x/plant_v7.2.scad
sensor/3d_case/plant_v7.x/plant_v7.2.stl
sensor/3d_case/plant_v7.x/plant_v7.3.scad
sensor/3d_case/plant_v7.x/plant_v7.3.stl
sensor/3d_case/plant_v7.x/plant_v7.4.scad
sensor/3d_case/plant_v7.x/plant_v7.5.scad
sensor/3d_case/plant_v8.0/holes.scad
sensor/3d_case/plant_v8.0/main-plant-sensor.scad
sensor/3d_case/plant_v8.0/sensor.scad
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

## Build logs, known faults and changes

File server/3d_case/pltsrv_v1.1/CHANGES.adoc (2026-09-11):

== Plant Server V1.1

* main.scad
** added labeled customizer section (poly quality, cut sliders, opening, print gap), mirroring the sensor case style
** added `_top` / `_bottom` toggles (equivalent of the sensor case's `_left` / `_right`) to show/hide each half independently
** added `_model_up` / `_model_down` toggles to show/hide the reference components independently by which half houses them (up: ESP + USB debug pcb, housed in the top; down: relay module, housed in the bottom)
** added `_print` toggle + `view_print()` to lay both halves flat, ready to slice (equivalent of the sensor case's `_print` / `view_print()`)
** renamed `cut_x`/`cut_y`/`cut_z`/`top_open` -> `_cut_x`/`_cut_y`/`_cut_z`/`_top_open` for naming consistency with the sensor case
* `view_print()` orientation (bottom floor-down as modeled, top flipped 180deg so its flat outer face sits on the bed) is a best-guess default, not verified against an actual slice/print -- no OpenSCAD CLI is available in this environment. Please check orientation in a slicer before printing.
** added `display_clip()` + 4 barbs on the display corner posts (`box_top`) so the display pcb clips into place when pushed up instead of just resting loose -- new `_dclip_*` customizer params to retune the fit. Barb height/position is derived from the T-Display S3 pcb geometry (61x25.7x1.2mm) assuming it sits flush against the display border when fully seated (`_top_open=0`); not verified against an actual print/fit, please check and retune `_dclip_*` if it's too tight/loose.
** fix (v2): barb was on the wrong side of the post (reaching in x, when the post sits outside the pcb's y edge, not its x edge) and one pcb-thickness too high -- now reaches in y off the post's y-face, and shifted down by 1.2mm so the ramp/catch sits against the pcb's bottom face instead of its top. Also had to shrink `_dclip_protrusion` (2.0 -> 0.3): the display_hole cut already removes material starting 0.35mm inside the pcb's edge, so there's only a thin window to reach into -- worth double-checking against the real board/print.
** fix (v3): display pads were too short to back up the barb -- their bottom (z=11.3) sat above the barb's ramp start (`_dclip_base_z`=10.4), leaving ~0.9mm of the barb unsupported/floating below the post. Pad bottom is now computed from `_dclip_base_z` (with a small margin) so it always reaches down far enough, and stays in sync if `_dclip_base_z` is retuned.
** fix (v4): the (9,14.5) corner pad+clip collided with the newly-enabled reset button (reset sits around x=6.5-10.5, y=10.85-13.85, z=12.6-14.6 in case coordinates) -- moved that corner to (14,14.5), 5mm further along the same edge, clear of the reset button's footprint. The other 3 corners are unchanged.
** added a pinhole for reset-button access -- same d=1 size convention as the sensor case's boot-button pinhole.
** fix: pinhole was drilled straight down through the top face, but the reset switch is side-actuated (actuator sticks out toward +y at y=12.85, not upward) -- redone as a horizontal hole along y, running from the outer wall (y=33) through the open cavity to the button.
** added a guide box (3x3mm, y=-33 to -12) around the pinhole so a pin has something to follow from the wall to near the button, instead of crossing open cavity blind. The pinhole cuts straight through it. Picks up a small notch near its far end (~1.7x0.5x3mm corner) from the pre-existing display-window cut, since the button sits right at that window's edge -- doesn't break the guide, just thins the wall on one side near the button.
** fix: that guide box actually ended 1.85mm *into* the button's own footprint (y=-13.85..-10.85, from its rst cube + body cube), not just close to it. Shortened to end at y=-14.85, keeping a clear 1mm margin from the button's nearest edge (-13.85). Side effect: the guide's y-range no longer reaches into the display-window cut at all, so the corner-notch issue above no longer applies either.
** extended the guide vertically (z 12.1-15.1 -> 12.1-20) so it's a rib fused to both the wall (y=-33) and the solid ceiling above (shell's own top face is at z=19.3), instead of a cantilever hanging off the wall alone with its far end floating in open cavity -- avoids needing print support under it.
** fix: that overshot the shell's own top face (19.3), poking 0.7mm out of the case -- this is a plain union, not something the outer shell clips, so anything added past its boundary just protrudes. Capped the guide back to z=12.1-19.3, flush with the top face instead of past it.
** fix: reset button was on the wrong side of the pcb along y. Flipped it in `sub_lilygo_t_display_s3.scad` (local y=-pcb[1]/2 -> +pcb[1]/2), which lands at case y=-12.85 once `render_model()`'s rotate([0,0,180]) is applied (not +12.85). Moved the pinhole to the -y side to match, and moved the display-corner-post fix from (9,14.5)->(14,14.5) back to (9,14.5), applying it instead to the corner that now actually collides: (9,-14.5)->(14,-14.5).
** added relay pcb locating pegs on `box_top`'s "relays pads" -- each pad ended flat with just the axial screw hole, now has a d=3mm peg (matching the relay pcb's own mounting-hole size, `holes[2]`) at its tip so it clips/registers the pcb instead of just resting on the flat face.
** added stiffener ribs to the same 4 relay pads (from a real print+assembly: they flex, being 31mm-long 4x4mm cantilevers hanging from the ceiling). Widened each pad to reach the nearest wall (y=+-33, only 8.3mm from holes[1]/2=24.7) over its upper half (z=3.08-18.58, the half nearer the ceiling anchor) -- roughly halves the effective unsupported length, which is what drives cantilever deflection. Ribs stop exactly at the wall (y=33/-33), not past it.
** increased rib height +20% (15.5mm -> ~18.6mm). Top stays anchored at the pad's own top (18.58, fused into the ceiling); the extra reach comes off the bottom instead (z 3.08-18.58 -> ~-0.02-18.58), extending further down the pad toward the pcb.
** added 4x d=3.6mm pump cable holes through box_bottom's -y wall (y=-33), for the relay outputs' cables running out to the pumps. Evenly spaced across the relay board's own width (66.5mm) at x=-24.9,-8.3,8.3,24.9, z=-14 -- the model doesn't capture individual relay terminal positions, so this is a reasonable default spacing, not tied to the real board's terminals. Check against the real board and retune if needed.
** fix: holes were too low. Raised z +15 (-14 -> 1). That needed `hcut` raised too (0.2 -> 0.6) to move the top/bottom split line up, giving box_bottom's own wall enough height to still be solid at the new hole position (new ceiling ~4.25, leaving ~3.25mm margin above the hole). Verified this only trims material off box_top's own outer wall below the new split -- box_top's own ceiling (z=19.3) is fixed regardless of hcut, everything it actually places (display, buttons, usb, reset guide) sits well above the new split, the relay pads/pegs/ribs/screw-hole are separate additions positioned by absolute z (unaffected either way), and the "insert" mating lip in both halves is computed from h/hcut so it tracks the new split line automatically.
** shortened box_bottom's matching peg ("support for replay PCB", the narrower r=1.3 cylinder) to make room -- z=-14->-14.5, h=2.9->1.9, so its top is now flush with its own shelf (z=-13.55) instead of poking up to z=-12.55. Leaves ~0.13mm clearance to the new peg above it. Check fit on a print.
** fix: after the usb-debug module moved +4.7mm (the earlier 7.5mm-gap fix), its outward connector now protrudes ~4.9mm past the case's +x wall.
** fix (v2, reverted the boss above): resized `main_vol`/`main_pos` instead -- `main_vol[0]` 100->104.9, `main_pos[0]` 4->6.45. Growing vol[0] by +4.9 while shifting pos[0] by +2.45 (half) keeps the -x wall anchored at its old position (-46, where the esp's far edge already only has ~0.5mm clearance) and moves only the +x wall out, to 58.9 -- flush with the connector. Widened `box_top`'s "large hole" and `box_bottom`'s "big hole for pcb" cavities by the same +4.9 (90->94.9) so their left edge stays anchored too, instead of encroaching on that same clearance from the cavity side. The mating "insert" lip scales with `main_vol[0]` automatically and stays centered on `main_pos`, so its margin from the wall (~3mm) comes out the same on both sides without a separate fix. No other content needed moving -- everything else (screw holes, pads, buttons, the reset pinhole) uses absolute coordinates independent of `main_vol`/`main_pos`.
** `view_print()`: buttons are now a separate part instead of being carried along inside `box_top`'s print transform.
** fix: the 180-on-x flip I added was wrong -- `box_top_buttons()`'s own local geometry already has the wide base at the bottom (z 15.1-17.7) and the narrow stem on top, so once separated from `box_top`'s rotation it needed no rotation at all, just a lift onto the bed. The flip had put the wide part on top instead. Removed it.
* geometry changed from v1.0: the display corner posts (added retention barbs), the ESP reference model (enabled the reset button), and the usb-debug module's position/mounting (see below) -- box_top/box_bottom volumes and all other holes/pads are unchanged
* fix (from a real print+assembly): the usb-debug module didn't plug fully into the ESP -- measured 7.5mm gap between the two pcbs' facing edges once actually mated. ESP pcb's facing edge is fixed at global x=20.5 (from its own dimensions), so `render_model()`'s usb_debug_pcb() translate moved from `26+7.5`=33.5 to 38.2 (+4.7mm) to put its facing edge at 20.5+7.5=28.0. Also shifted `box_top`'s "pcb-usb pads" and "screw pcb-usb pads" by the same +4.7mm (40.5->45.2, 25.5->30.2) since they were positioned to match the board's old (wrong) mounting-hole locations -- otherwise the screw posts wouldn't line up with the corrected board. Side effect: the module's outward-facing usb connector now lands much closer to the case's fixed USB-hole cutout (was 5mm short of it, now only 0.35mm short) -- an improvement, not something that needed a separate fix.
* fix (from the same print+assembly): the two plastic top buttons pressed too hard against their pcb buttons. `box_top_buttons()`'s base (the large flange, was `[4,6,2.6]`) made 0.5mm thinner (`[4,6,2.1]`), keeping its top face fixed (where it merges with the stem) and raising the pcb-contact face by 0.5mm instead. The stem originally shared that same bottom face -- shortened it by the same 0.5mm (`[2.8,2.8,5]` -> `[2.8,2.8,4.5]`, top fixed) so it doesn't poke out below the base as a new, much smaller contact point. `view_print()`'s btn_lift updated to match (15.1 -> 15.6).
* sub_lilygo_t_display_s3.scad: enabled the `reset button` block (was copy-pasted in from the older, non-S3 t_display module and left commented out). Position (`-pcb[0]/2+12`, bottom long edge) is inherited unadapted from that module -- worth checking against the real T-Display S3 board layout. Note: `box_top` doesn't yet have a matching pinhole/case opening for it, only for the two existing `bt` buttons.

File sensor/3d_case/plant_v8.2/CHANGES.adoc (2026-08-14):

== Plant Sensor V8.2

* fix pin hole button access (only boot button was accessible in 8.1)

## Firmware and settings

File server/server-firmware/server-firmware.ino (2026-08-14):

// WiFi + BLE + Display + Buttons isolation test — Gardener and WaterPumps still disabled.

#include <Arduino.h>
#include "Config.h"
#include "Secrets.h"
#include "Store.h"
#include "BlueC.h"
#include "Display.h"
#include "WaterPumps.h"
#include "Gardener.h"
#include <WifiManager.h>
#include <PrometheusServer.h>
#include <AceButton.h>

using namespace ace_button;

Store store;
BlueC bluec(store);
Display display;
WaterPumps pumps(27, 26, 25, 33);
Gardener gardener(pumps, display, 25, COOLDOWN_MS);
WifiManager wifiManager(SECRET_SSID, SECRET_PASS);

static String buildMetrics(PrometheusServer& prom) {
  return store.buildMetrics(prom);
}
PrometheusServer promSrv(buildMetrics);

ButtonConfig buttonConfig;
AceButton btn1(&buttonConfig, 14); // DOWN
AceButton btn2(&buttonConfig, 0);  // UP (BOOT)

static UIMode _uiMode  = RUN;

static void setUIMode(UIMode mode) {
  if (_uiMode != mode) {
    _uiMode = mode;
    const char* modeStr = "";
    switch (_uiMode) {
      case RUN:                 modeStr = "Mode: RUN"; break;
      case SETUP_NAV:           modeStr = "Mode: SETUP NAV"; break;
      case SENSOR_SETUP:        modeStr = "Mode: SENSOR SETUP"; break;
      case SENSOR_SETTINGS_NAV: modeStr = "Mode: SETTINGS NAV"; break;
      case SENSOR_SETTING_EDIT: modeStr = "Mode: SETTING EDIT"; break;
      case WATERING_SETUP:      modeStr = "Mode: WATER SETUP"; break;
    }
    display.log(modeStr);
    Serial.println(modeStr);
  }
}
static int    _setupBox  = 1;
static int    _setupStep = 0;
static int    _activeSettingLine = 1; // 1=Pump, 2=Threshold, 3=Duration, 4=Delete
static bool   _deleteConfirm = false;
static SensorReading _tempConfig;

static int           _sensorIdx          = 0;
static unsigned long _lastSensorRefresh  = 0;
static const unsigned long SENSOR_REFRESH_MS = 15000;

static const char* getHumidityStateStr(HumidityState state) {
  switch (state) {
    case HUMIDITY_DRY:      return "DRY";
    case HUMIDITY_THIRSTY:  return "THIRSTY";
    case HUMIDITY_HEALTHY:  return "HEALTHY";
    case HUMIDITY_UNKNOWN:  
    default:                return "UNKNOWN";
  }
}

static const char* getWateringStateStr(WateringState state) {
  switch (state) {
    case WATERING_ACTIVE:          return "ACTIVE";
    case WATERING_COOLDOWN:        return "COOLDOWN";
    case WATERING_WAIT_MEASUREMENT: return "WAIT_MEASUREMENT";
    case WATERING_IDLE:
    default:                       return "IDLE";
  }
}

static void _logSensorState(const SensorReading& r) {
  if (ENABLE_DEBUG_GARDENER) {
    char msg[64];
    snprintf(msg, sizeof(msg), "%s: H:%s W:%s", r.name, getHumidityStateStr(r.humidityState), getWateringStateStr(r.wateringState));
    display.log(msg);
  }
}

static void _showCurrentSensor(bool loggedByButton = false) {
  store.lock();
  const auto& all = store.getAll();
  if (all.empty()) {
    display.showNoSensors();
    store.unlock();
    return;
  }
  if (_sensorIdx >= (int)all.size()) _sensorIdx = 0;
  if (_sensorIdx < 0) _sensorIdx = (int)all.size() - 1;
  auto it = all.begin();
  std::advance(it, _sensorIdx);

  if (_uiMode == SENSOR_SETTINGS_NAV || _uiMode == SENSOR_SETTING_EDIT) {
    display.showSensor(_tempConfig, _sensorIdx + 1, (int)all.size());
    display.setDeleteConfirm(_deleteConfirm);
    display.setSettingsFocus(_activeSettingLine, _uiMode == SENSOR_SETTING_EDIT);
  } else {
    display.showSensor(it->second, _sensorIdx + 1, (int)all.size());
    display.setDeleteConfirm(false);
    display.setSettingsFocus(0, false);
  }

  display.setSelectedPlant(_sensorIdx);
  _lastSensorRefresh = millis();

  if (loggedByButton) {
    _logSensorState(it->second);
  }

  store.unlock();
}

static void onButtonEvent(AceButton* btn, uint8_t eventType, uint8_t /*buttonState*/) {
  display.wake();
  Serial.println("click");
  if (_uiMode == RUN) {
    if (eventType == AceButton::kEventReleased) {
      if (btn->getPin() == 0) {
        // UP button released: cycle forward through sensors
        _sensorIdx++;
        _showCurrentSensor(true);
      }
    } else if (eventType == AceButton::kEventLongPressed && btn->getPin() == 14) {
      // DOWN button long-pressed: enter box selection mode
      setUIMode(SETUP_NAV);
      _setupBox = 1;
      display.highlightBox(_setupBox);
    }
  } else if (_uiMode == SETUP_NAV) {
    if (eventType == AceButton::kEventReleased) {
      if (btn->getPin() == 0) {
        // UP button released: cycle highlighted boxes indefinitely
        _setupBox++;
        if (_setupBox > 3) {
          _setupBox = 1;
        }
        display.highlightBox(_setupBox);
      } else if (btn->getPin() == 14) {
        // DOWN button released: select box
        if (_setupBox == 1) {
          setUIMode(SENSOR_SETUP);
          display.highlightBox(1);
          display.setSettingsMode(true);
          _showCurrentSensor();
        } else {
          setUIMode(RUN);
          display.highlightBox(0);
          display.setSettingsMode(false);
          _showCurrentSensor();
        }
      }
    } else if (eventType == AceButton::kEventLongPressed) {
      // Long-press either button: exit box selection mode
      setUIMode(RUN);
      display.highlightBox(0);
      display.setSettingsMode(false);
      _showCurrentSensor();
    }
  } else if (_uiMode == SENSOR_SETUP) {
    if (eventType == AceButton::kEventReleased) {
      if (btn->getPin() == 14) {
        // DOWN button released: enter settings navigation mode for the current sensor
        store.lock();
        const auto& all = store.getAll();
        if (!all.empty()) {
          auto it = all.begin();
          std::advance(it, _sensorIdx);
          _tempConfig = it->second;
          _deleteConfirm = false;
          setUIMode(SENSOR_SETTINGS_NAV);
          _activeSettingLine = 1; // start on Pump
          _showCurrentSensor();
        }
        store.unlock();
      } else if (btn->getPin() == 0) {
        // UP button released: cycle through sensors
        _sensorIdx++;
        _showCurrentSensor(true);
      }
    } else if (eventType == AceButton::kEventLongPressed) {
      // Long-press either button: exit to run mode
      setUIMode(RUN);
      display.highlightBox(0);
      display.setSettingsMode(false);
      _showCurrentSensor();
    }
  } else if (_uiMode == SENSOR_SETTINGS_NAV) {
    if (eventType == AceButton::kEventReleased) {
      if (btn->getPin() == 0) {
        // UP button released: cycle active setting line
        _activeSettingLine++;
        if (_activeSettingLine > 4) {
          _activeSettingLine = 1;
        }
        _showCurrentSensor();
      } else if (btn->getPin() == 14) {
        // DOWN button released: select setting to edit
        if (_activeSettingLine == 4) {
          _deleteConfirm = false;
        }
        setUIMode(SENSOR_SETTING_EDIT);
        _showCurrentSensor();
      }
    } else if (eventType == AceButton::kEventLongPressed) {
      // Long-press either button: exit back to SENSOR_SETUP
      setUIMode(SENSOR_SETUP);
      _showCurrentSensor();
    }
  } else if (_uiMode == SENSOR_SETTING_EDIT) {
    if (eventType == AceButton::kEventReleased) {
      if (btn->getPin() == 0) {
        // UP button released: increment value / toggle delete confirm (looping)
        if (_activeSettingLine == 1) {
          _tempConfig.pumpIndex++;
          if (_tempConfig.pumpIndex > 3) _tempConfig.pumpIndex = -1;
        } else if (_activeSettingLine == 2) {
          _tempConfig.moistureThreshold += 5;
          if (_tempConfig.moistureThreshold > 100) _tempConfig.moistureThreshold = 0;
        } else if (_activeSettingLine == 3) {
          _tempConfig.durationSeconds += 5;
          if (_tempConfig.durationSeconds > 60) _tempConfig.durationSeconds = 5;
        } else if (_activeSettingLine == 4) {
          _deleteConfirm = !_deleteConfirm;
        }
        _showCurrentSensor();
      } else if (btn->getPin() == 14) {
        // DOWN button released: save value / delete sensor
        if (_activeSettingLine == 4) {
          if (_deleteConfirm) {
            // Delete sensor!
            store.remove(_tempConfig.name);
            _sensorIdx = 0;
            
            store.lock();
            bool empty = store.getAll().empty();
            store.unlock();

            if (empty) {
              setUIMode(RUN);
              display.setSettingsMode(false);
            } else {
              setUIMode(SENSOR_SETUP);
            }
            _showCurrentSensor();
            return;
          } else {
            setUIMode(SENSOR_SETTINGS_NAV);
            _showCurrentSensor();
          }
        } else {
          _tempConfig.lastSeen = 0; // sentinel: config-only update
          store.update(_tempConfig);
          setUIMode(SENSOR_SETTINGS_NAV);
          _showCurrentSensor();
        }
      }
    } else if (eventType == AceButton::kEventLongPressed) {
      // Long-press either button: discard edits by reloading from store
      if (_activeSettingLine == 4) {
        _deleteConfirm = false;
      } else {
        store.lock();
        const auto& all = store.getAll();
        if (!all.empty()) {
          auto it = all.begin();
          std::advance(it, _sensorIdx);
          _tempConfig = it->second;
        }
        store.unlock();
      }
      setUIMode(SENSOR_SETTINGS_NAV);
      _showCurrentSensor();
    }
  } else if (_uiMode == WATERING_SETUP) {
    if (eventType == AceButton::kEventReleased) {
      if (btn->getPin() == 0) {
        if (_setupStep == 0) {
          _tempConfig.pumpIndex++;
          if (_tempConfig.pumpIndex > 3) _tempConfig.pumpIndex = -1;
        } else if (_setupStep == 1) {
          _tempConfig.moistureThreshold += 5;
          if (_tempConfig.moistureThreshold > 100) _tempConfig.moistureThreshold = 0;
        } else if (_setupStep == 2) {
          _tempConfig.durationSeconds += 5;
          if (_tempConfig.durationSeconds > 60) _tempConfig.durationSeconds = 5;
        }
      } else {
        _setupStep++;
        if (_setupStep > 2) {
          _tempConfig.lastSeen = 0; // sentinel: config-only update, preserve BLE data
          store.update(_tempConfig);
          setUIMode(RUN);
          display.highlightBox(0);
          _showCurrentSensor();
        }
      }
    }
  }
}

static void onWifiStateChange(WifiManager::State state) {
  if (state == WifiManager::CONNECTED) {
    char msg[48];
    snprintf(msg, sizeof(msg), "IP: %s", WiFi.localIP().toString().c_str());
    display.log(msg);
    bluec.startScan(); // WiFi is connected, resume BLE scanning
  } else if (state == WifiManager::CONNECTING) {
    bluec.stopScan();  // WiFi is actively connecting, pause BLE scanning to reduce RF contention
  } else if (state == WifiManager::FAILED || state == WifiManager::DISCONNECTED) {
    if (state == WifiManager::FAILED) {
      display.log("WiFi lost");
    }
    bluec.startScan(); // WiFi is in waiting/back-off phase, keep BLE active for local monitoring
  }
}

void setup() {
  Serial.begin(115200);
  delay(2000);

  // LilyGo T-Display-S3: LCD power rail
  pinMode(15, OUTPUT);
  digitalWrite(15, HIGH);

  Serial.println("[BOOT] WiFi+BLE+Display+Buttons isolation test");
  store.begin();
  display.init();
  gardener.init();
  bluec.init(); // Initialize BLE first so state changes in wifiManager can safely trigger BLE scan actions
  wifiManager.onStateChange(onWifiStateChange);
  wifiManager.init();
  promSrv.init();

  pinMode(14, INPUT_PULLUP);
  pinMode(0,  INPUT_PULLUP);
  buttonConfig.setEventHandler(onButtonEvent);
  buttonConfig.setFeature(ButtonConfig::kFeatureLongPress);
  buttonConfig.setFeature(ButtonConfig::kFeatureSuppressAfterLongPress);

  _showCurrentSensor();
  Serial.println("[BOOT] Running");
}

void loop() {
  if (_uiMode == RUN) {
    display.setButtonLabels("CYCLE", "", "", "SETUP");
  } else if (_uiMode == SETUP_NAV) {
    display.setButtonLabels("CYCLE", "EXIT", "SELECT", "EXIT");
  } else if (_uiMode == SENSOR_SETUP) {
    display.setButtonLabels("CYCLE", "EXIT", "SELECT", "EXIT");
  } else if (_uiMode == SENSOR_SETTINGS_NAV) {
    display.setButtonLabels("CYCLE", "EXIT", "EDIT", "EXIT");
  } else if (_uiMode == SENSOR_SETTING_EDIT) {
    display.setButtonLabels("CHANGE", "CANCEL", "SAVE", "CANCEL");
  } else if (_uiMode == WATERING_SETUP) {
    display.setButtonLabels("CHANGE", "", "NEXT", "");
  }

  btn1.check();
  btn2.check();
  wifiManager.loop();
  promSrv.loop();
  gardener.loop(store);

  if (!display.isDisplayOff()) {
    if (_uiMode == RUN) {
      if (millis() - _lastSensorRefresh >= SENSOR_REFRESH_MS) {
        _sensorIdx++;
        _showCurrentSensor();
      }
      display.update(store);
    } else if (_uiMode == WATERING_SETUP) {
      display.showWateringSetup(_tempConfig, _setupStep);
    } else {
      display.update(store);
    }
  } else {
    display.update(store);
  }
}

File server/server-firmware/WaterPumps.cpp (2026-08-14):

#include "WaterPumps.h"

WaterPumps::WaterPumps(int p1, int p2, int p3, int p4) {
  _pins[0] = p1;
  _pins[1] = p2;
  _pins[2] = p3;
  _pins[3] = p4;
}

void WaterPumps::init() {
  // Passive mode: do not write to physical GPIO pins
  /*
  for (int i = 0; i < 4; i++) {
    pinMode(_pins[i], OUTPUT);
    digitalWrite(_pins[i], OFF_LEVEL);
  }
  */
}

void WaterPumps::setPump(int index, bool on) {
  if (index < 0 || index >= 4) return;
  // Passive mode: do not write to physical GPIO pins
  // digitalWrite(_pins[index], on ? ON_LEVEL : OFF_LEVEL);
}

void WaterPumps::allOff() {
  // Passive mode: do not write to physical GPIO pins
  /*
  for (int i = 0; i < 4; i++) {
    digitalWrite(_pins[i], OFF_LEVEL);
  }
  */
}

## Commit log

2026-08-14 inital - sensor
2026-09-11 case update
    [main.scad, pltsrv_v1.1.3mf, pltsrv_v1.1.stl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]
